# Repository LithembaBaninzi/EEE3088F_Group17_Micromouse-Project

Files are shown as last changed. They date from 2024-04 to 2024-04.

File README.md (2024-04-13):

# EEE3088F_Group17_Micromouse-Project
Designing a micromouse

## Project Overview

Welcome to the Micro-Mouse project for the year 2024! This project involves building subassemblies for your very own simplified micro-mouse, a maze-solving robot. While your micro-mouse may not match the speed of those featured in popular videos, this project serves as an exciting opportunity to delve into hardware design and some minor software components. Let's get started!



### Subsystem Specifications

Detailed specifications and requirements for each subsystem are provided, including pinouts, connector types, power requirements, and considerations for design and functionality.

### Modules Description

#### 1. The Motherboard

- **Description**: The motherboard serves as the base board connecting all other PCBs together.
- **Interface Description**: 
  - Processor board: Two 2x19 (2.54mm pin pitch) pin headers.
  - Motors: Two 2x1 (2.54mm pin pitch) pin headers.
  - Sensor board: 2x14 (2.54mm pin pitch) pin headers.
  - Power board: 2x8 (2.54mm pin pitch) pin headers.



#### 2. The Processor

- **Description**: The processor board features an STM32L476 microcontroller.
- **Interface**: Detailed pinouts are provided for connections.



#### 3. Power Module

- **Description**: Responsible for powering the entire system and charging the battery.
- **Requirements**:
  - Operate 2 motors within specified parameters.
  - Provide analog connection for battery voltage monitoring.
  - Charge the battery from the 5V input pin.
  - Include an ON/OFF switch.



#### 4. Sensor Module

- **Description**: Responsible for detecting/sensing objects in the micro-mouse's path.
- **Requirements**:
  - Detect obstacles in front and possibly on the sides.
  - Design for reliability and power efficiency.
  - Interface with the processor to indicate sensed obstacles.



#### The maze
The maze will have dead ends, multiple paths to the finishing area with each pixel being a 200mm square.
There are multiple paths to get to the goal.
An example is provided below:



## Resources

- [Veritasium Video](https://www.youtube.com/watch?v=JnkMyfQ5YfY) - Watch this video to understand the concept of a micro-mouse.
- Additional resources and documentation are provided within the project repository.

## Conclusion

This README provides an overview of the Micro-Mouse project for 2024, outlining the objectives, module descriptions, and project requirements. Each subsystem has specific tasks and considerations to ensure successful integration into the micro-mouse design. For further details, refer to the project documentation and resources provided. Happy building!
```

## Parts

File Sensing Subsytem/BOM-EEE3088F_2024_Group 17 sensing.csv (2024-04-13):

Comment | Designator | Footprint | LCSC
TEFT4300 | F_R1,L_R1,R_R2 | XDCR_TEFT4300 | C118301
100k | R_FR3,R_LR3,R_RR3 | R_0805_2012Metric | C149504
82 | R_FPD1,R_LPD1,R_RPD1 | R_0805_2012Metric | C17408
10k | R_FR2,R_LR2,R_RR2 | R_0805_2012Metric | C17414
150 | R_F1,R_L1,R_R1 | R_0805_2012Metric | C17471
1.8k | R_FR1,R_LR1,R_RR1 | R_0805_2012Metric | C17513
13 | R_F_EM1,R_L_EM1,R_R_EM1 | R_0805_2012Metric | C17544
4.7u | C_EM1,C_EM2,C_EM5 | C_0805_2012Metric | C1779
2N2222A | FQ1,LQ1,RQ1 | TO92254P470H750-3 | C20616319
0.1u | C_EM3,C_EM4,C_EM6 | C_0805_2012Metric | C49678
TSAL4400 | F_LED1,L_LED1,R_LED1 | LED_D3.0mm_Horizontal_O1.27mm_Z2.0mm_IRBlack | C94135
JP9 | 10k_JP3 | SolderJumper-2_P1.3mm_Open_RoundedPad1.0x1.5mm
TP3 | VoutL_TP1 | TestPoint_Pad_D2.0mm
JP5 | 10k_JP1 | SolderJumper-2_P1.3mm_Open_RoundedPad1.0x1.5mm
IcL_TP | TP1 | TestPoint_Pad_D2.0mm
TP6 | VoutR_TP1 | TestPoint_Pad_D2.0mm
TP4 | VoutF_TP1 | TestPoint_Pad_D2.0mm
JP6 | 10k_JP2 | SolderJumper-2_P1.3mm_Open_RoundedPad1.0x1.5mm

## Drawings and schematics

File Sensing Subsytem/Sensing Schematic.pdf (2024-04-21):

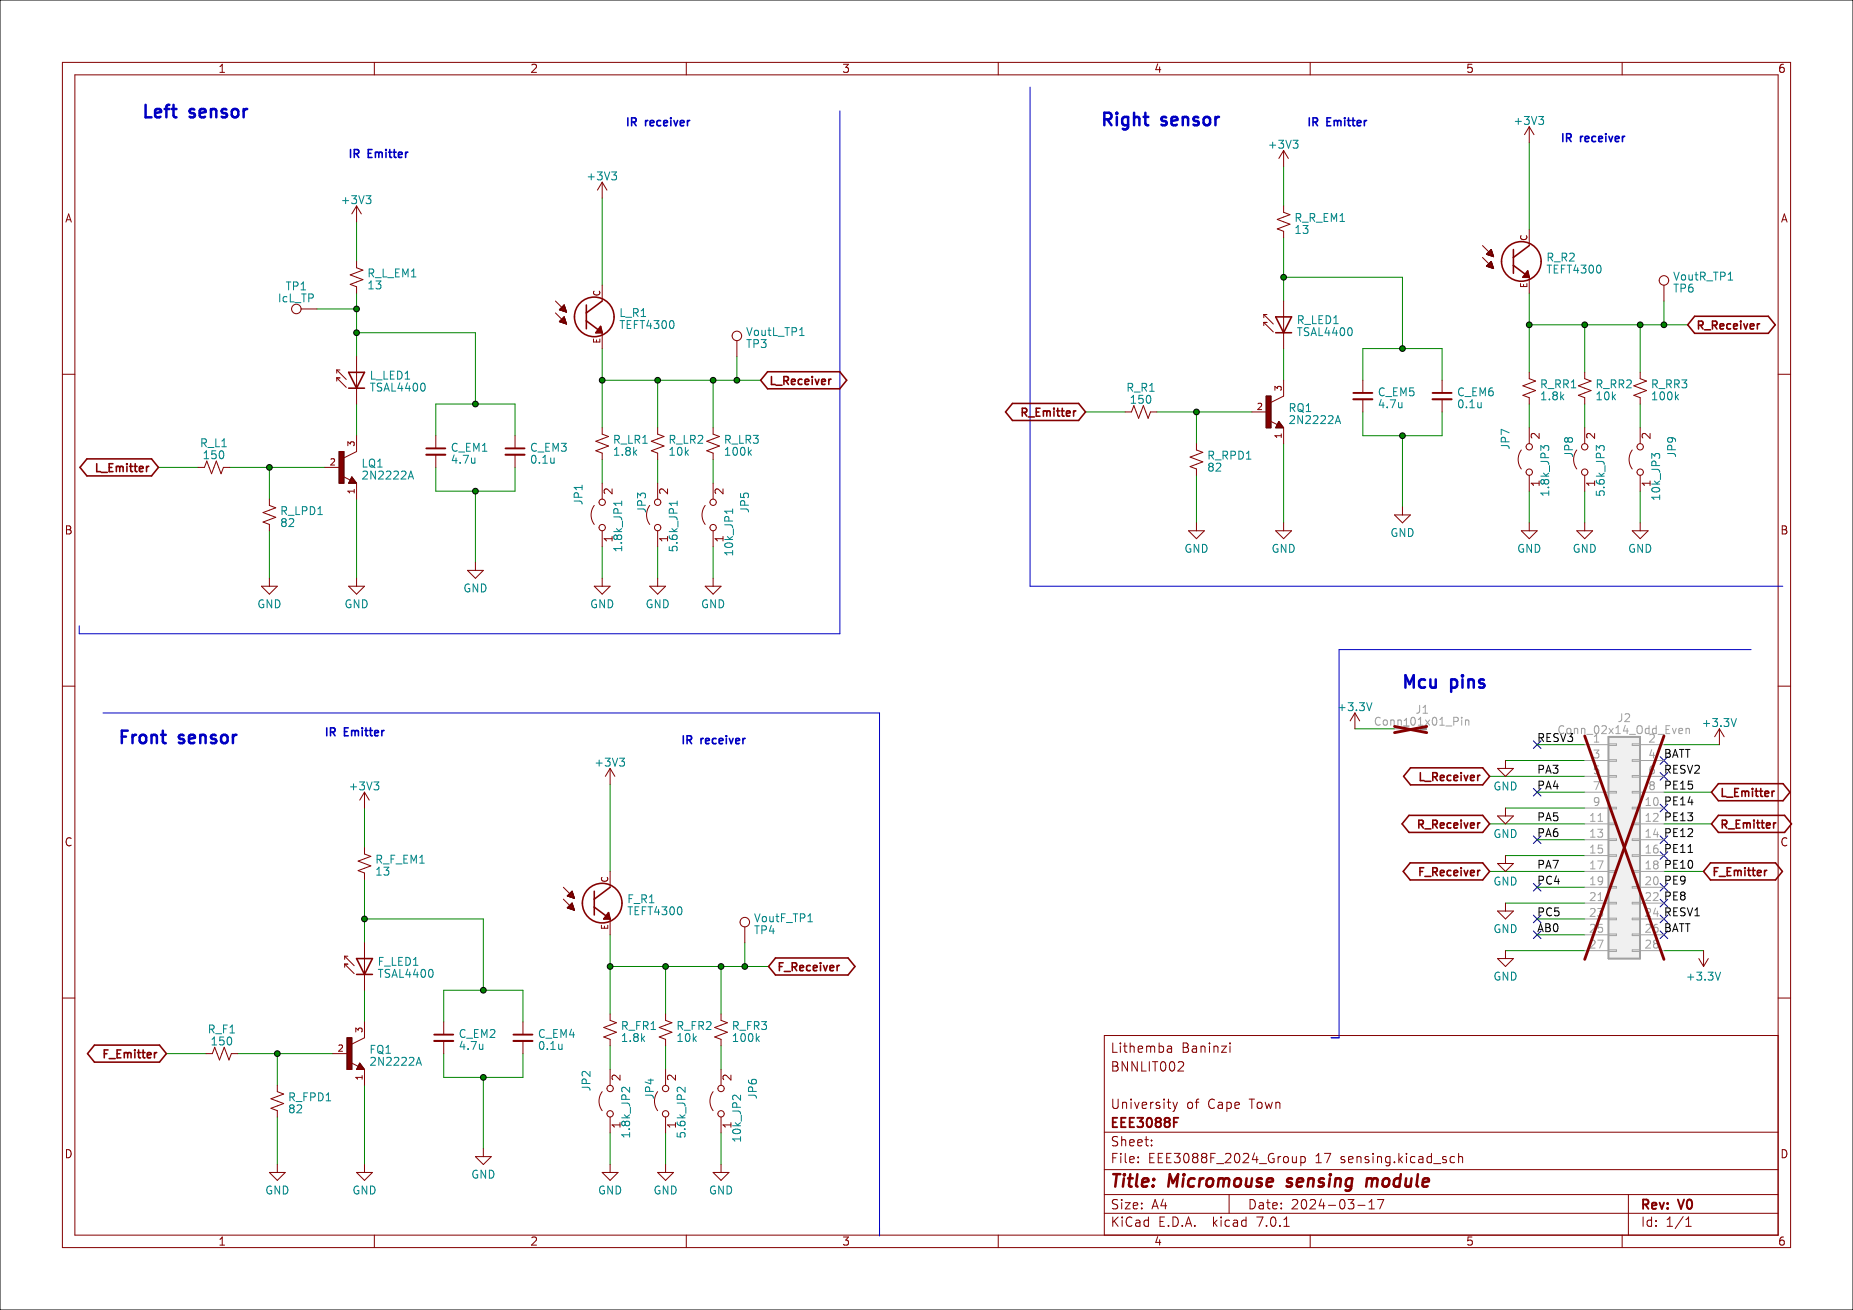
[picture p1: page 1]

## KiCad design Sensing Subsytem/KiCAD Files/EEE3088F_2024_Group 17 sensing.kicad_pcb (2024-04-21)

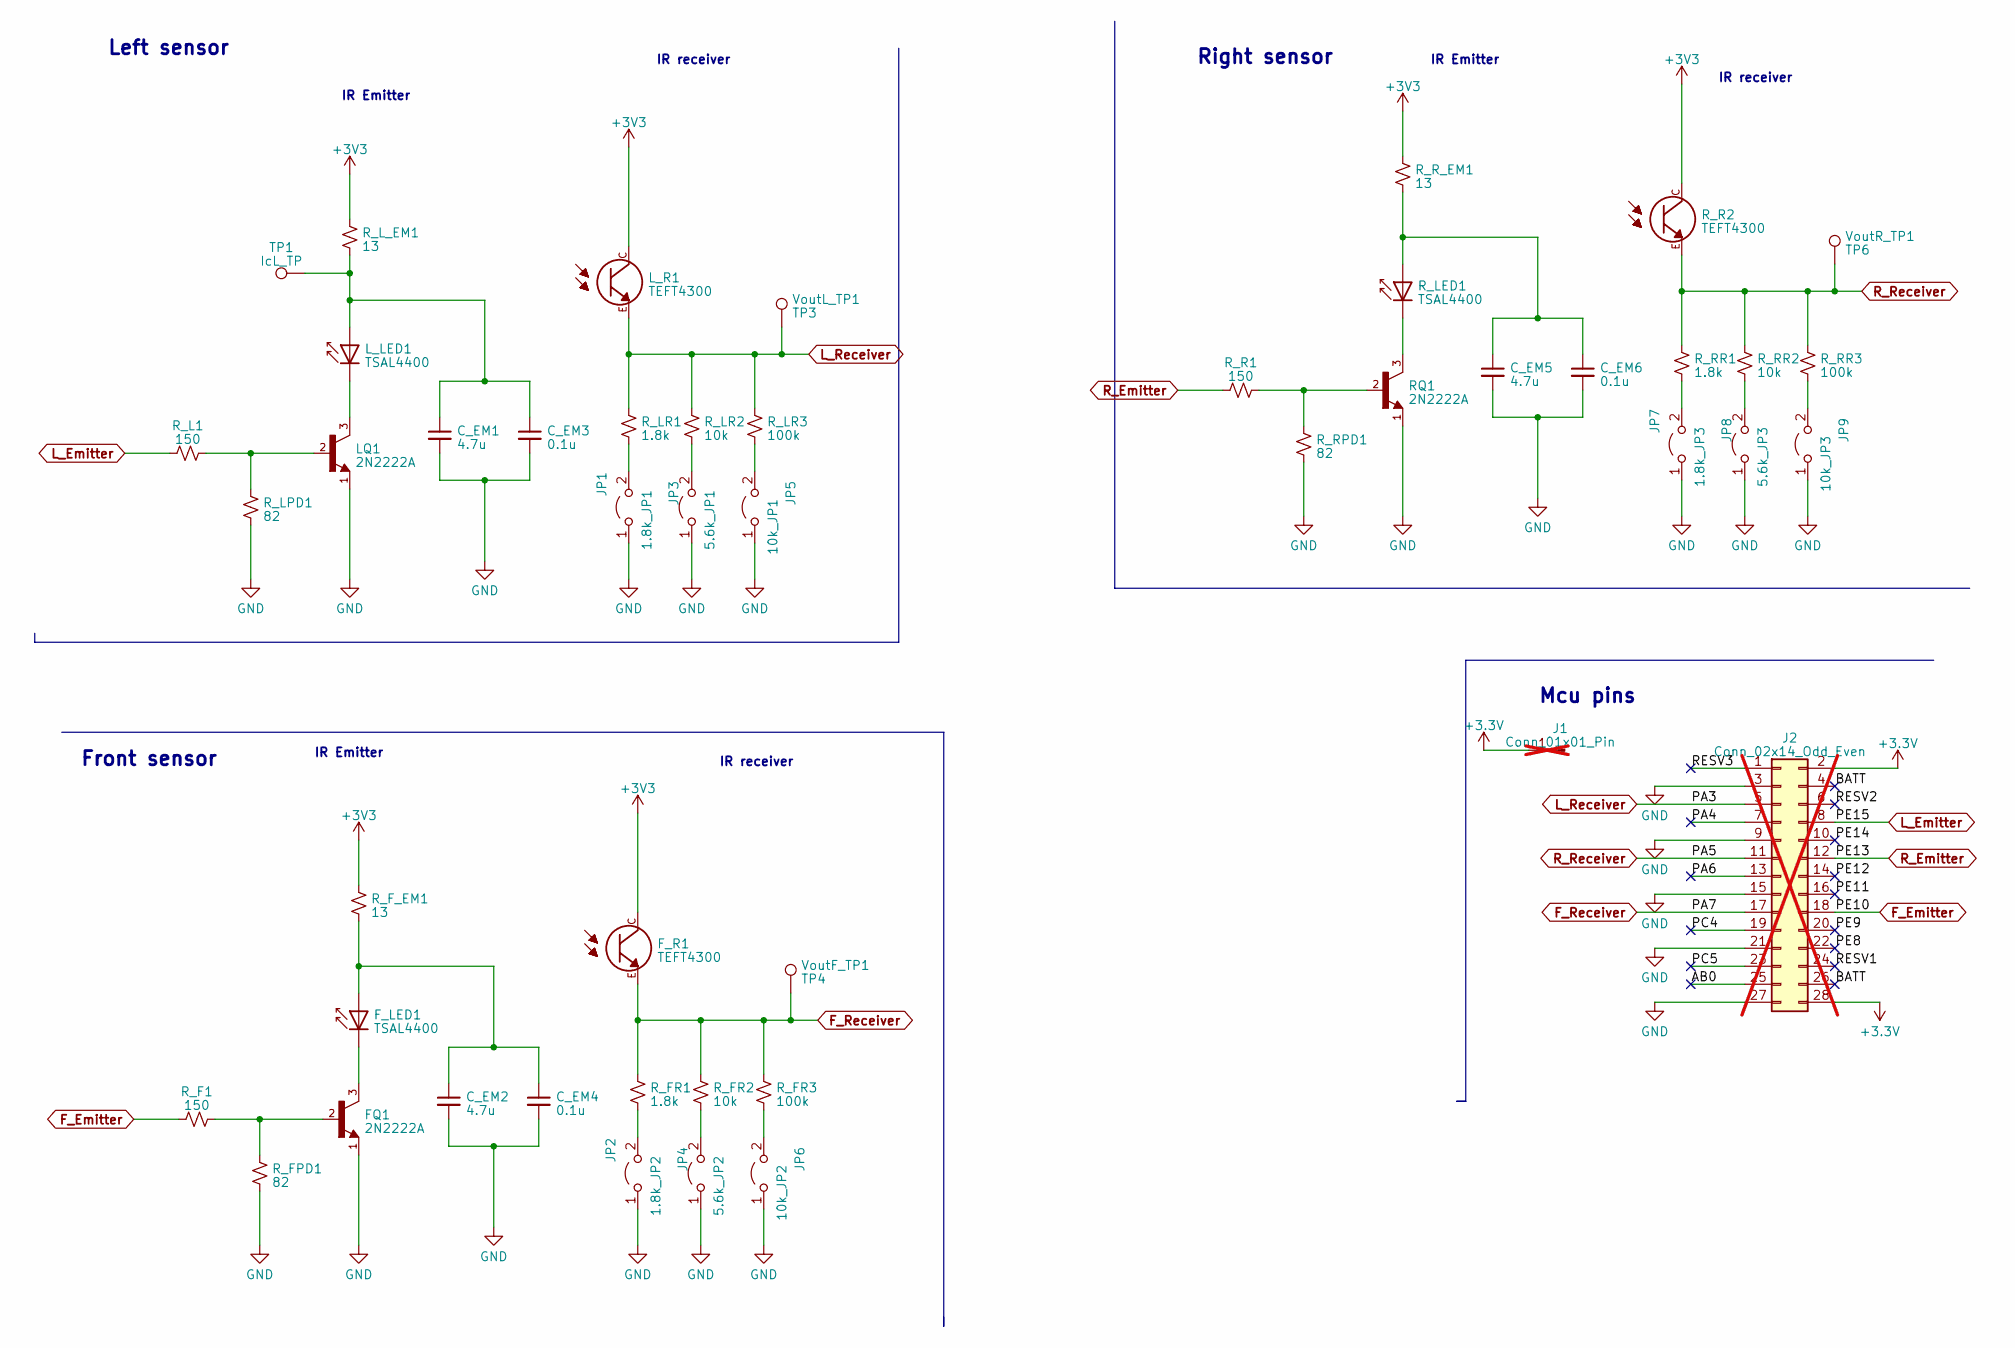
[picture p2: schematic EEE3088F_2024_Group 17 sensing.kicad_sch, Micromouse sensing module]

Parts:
1.8k_JP1: JP1; SolderJumper-2_P1.3mm_Open_RoundedPad1.0x1.5mm
1.8k_JP2: JP2; SolderJumper-2_P1.3mm_Open_RoundedPad1.0x1.5mm
1.8k_JP3: JP7; SolderJumper-2_P1.3mm_Open_RoundedPad1.0x1.5mm
5.6k_JP1: JP3; SolderJumper-2_P1.3mm_Open_RoundedPad1.0x1.5mm
5.6k_JP2: JP4; SolderJumper-2_P1.3mm_Open_RoundedPad1.0x1.5mm
5.6k_JP3: JP8; SolderJumper-2_P1.3mm_Open_RoundedPad1.0x1.5mm
10k_JP1: JP5; SolderJumper-2_P1.3mm_Open_RoundedPad1.0x1.5mm
10k_JP2: JP6; SolderJumper-2_P1.3mm_Open_RoundedPad1.0x1.5mm
10k_JP3: JP9; SolderJumper-2_P1.3mm_Open_RoundedPad1.0x1.5mm
C_EM1, C_EM2, C_EM5: 4.7u; C_0201_0603Metric
C_EM3, C_EM4, C_EM6: 0.1u; C_0201_0603Metric
FQ1: 2N2222A; TO92254P470H750-3; PARTREV N/A
F_LED1: TSAL4400; LED_D3.0mm_Horizontal_O1.27mm_Z2.0mm_IRBlack
F_R1: TEFT4300; XDCR_TEFT4300
J1: Conn_01x01_Pin; PinHeader_1x01_P2.54mm_Vertical; not fitted
J2: Conn_02x14_Odd_Even; PinHeader_2x14_P2.54mm_Vertical; not fitted
LQ1: 2N2222A; TO92254P470H750-3; PARTREV N/A
L_LED1: TSAL4400; LED_D3.0mm_Horizontal_O1.27mm_Z2.0mm_IRBlack
L_R1: TEFT4300; XDCR_TEFT4300
RQ1: 2N2222A; TO92254P470H750-3; PARTREV N/A
R_F1: 150; R_0805_2012Metric
R_FPD1: 82; R_0805_2012Metric
R_FR1: 1.8k; R_0805_2012Metric
R_FR2: 10k; R_0805_2012Metric
R_FR3: 100k; R_0805_2012Metric
R_F_EM1: 13; R_0805_2012Metric
R_L1: 150; R_0805_2012Metric
R_LED1: TSAL4400; LED_D3.0mm_Horizontal_O1.27mm_Z2.0mm_IRBlack
R_LPD1: 82; R_0805_2012Metric
R_LR1: 1.8k; R_0805_2012Metric
R_LR2: 10k; R_0805_2012Metric
R_LR3: 100k; R_0805_2012Metric
R_L_EM1: 13; R_0805_2012Metric
R_R1: 150; R_0805_2012Metric
R_R2: TEFT4300; XDCR_TEFT4300
R_RPD1: 82; R_0805_2012Metric
R_RR1: 1.8k; R_0805_2012Metric
R_RR2: 10k; R_0805_2012Metric
R_RR3: 100k; R_0805_2012Metric
R_R_EM1: 13; R_0805_2012Metric
TP1: IcL_TP; TestPoint_Pad_D2.0mm
VoutF_TP1: TP4; TestPoint_Pad_D2.0mm
VoutL_TP1: TP3; TestPoint_Pad_D2.0mm
VoutR_TP1: TP6; TestPoint_Pad_D2.0mm

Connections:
+3.3V: J1.1, J2.2, J2.28
+3V3: F_R1.C, L_R1.C, R_F_EM1.1, R_L_EM1.1, R_R2.C, R_R_EM1.1
/AB0: J2.25
/BATT: J2.4, J2.26
/PA4: J2.7
/PA6: J2.13
/PC4: J2.19
/PC5: J2.23
/PE8: J2.22
/PE9: J2.20
/PE11: J2.16
/PE12: J2.14
/PE14: J2.10
/RESV1: J2.24
/RESV2: J2.6
/RESV3: J2.1
F_Emitter: J2.18, R_F1.1
F_Receiver: F_R1.E, J2.17, R_FR1.1, R_FR2.1, R_FR3.1, VoutF_TP1.1
GND: 1.8k_JP1.1 (A), 1.8k_JP2.1 (A), 1.8k_JP3.1 (A), 5.6k_JP1.1 (A), 5.6k_JP2.1 (A), 5.6k_JP3.1 (A), 10k_JP1.1 (A), 10k_JP2.1 (A), 10k_JP3.1 (A), C_EM1.2, C_EM2.2, C_EM3.2, C_EM4.2, C_EM5.2, C_EM6.2, FQ1.1, J2.3, J2.9, J2.15, J2.21, J2.27, LQ1.1, RQ1.1, R_FPD1.2, R_LPD1.2, R_RPD1.2
L_Emitter: J2.8, R_L1.1
L_Receiver: J2.5, L_R1.E, R_LR1.1, R_LR2.1, R_LR3.1, VoutL_TP1.1
unnamed: 1.8k_JP1.2 (B), R_LR1.2
unnamed: 1.8k_JP2.2 (B), R_FR1.2
unnamed: 1.8k_JP3.2 (B), R_RR1.2
unnamed: 5.6k_JP1.2 (B), R_LR2.2
unnamed: 5.6k_JP2.2 (B), R_FR2.2
unnamed: 5.6k_JP3.2 (B), R_RR2.2
unnamed: 10k_JP1.2 (B), R_LR3.2
unnamed: 10k_JP2.2 (B), R_FR3.2
unnamed: 10k_JP3.2 (B), R_RR3.2
unnamed: FQ1.2, R_F1.2, R_FPD1.1
unnamed: C_EM2.1, C_EM4.1, F_LED1.2 (A), R_F_EM1.2
unnamed: FQ1.3, F_LED1.1 (K)
unnamed: LQ1.2, R_L1.2, R_LPD1.1
unnamed: C_EM1.1, C_EM3.1, L_LED1.2 (A), R_L_EM1.2, TP1.1
unnamed: LQ1.3, L_LED1.1 (K)
unnamed: RQ1.2, R_R1.2, R_RPD1.1
unnamed: C_EM5.1, C_EM6.1, R_LED1.2 (A), R_R_EM1.2
unnamed: RQ1.3, R_LED1.1 (K)
R_Emitter: J2.12, R_R1.1
R_Receiver: J2.11, R_R2.E, R_RR1.1, R_RR2.1, R_RR3.1, VoutR_TP1.1

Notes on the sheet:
IR Emitter
IR receiver
Right sensor
Left sensor
Mcu pins
Front sensor

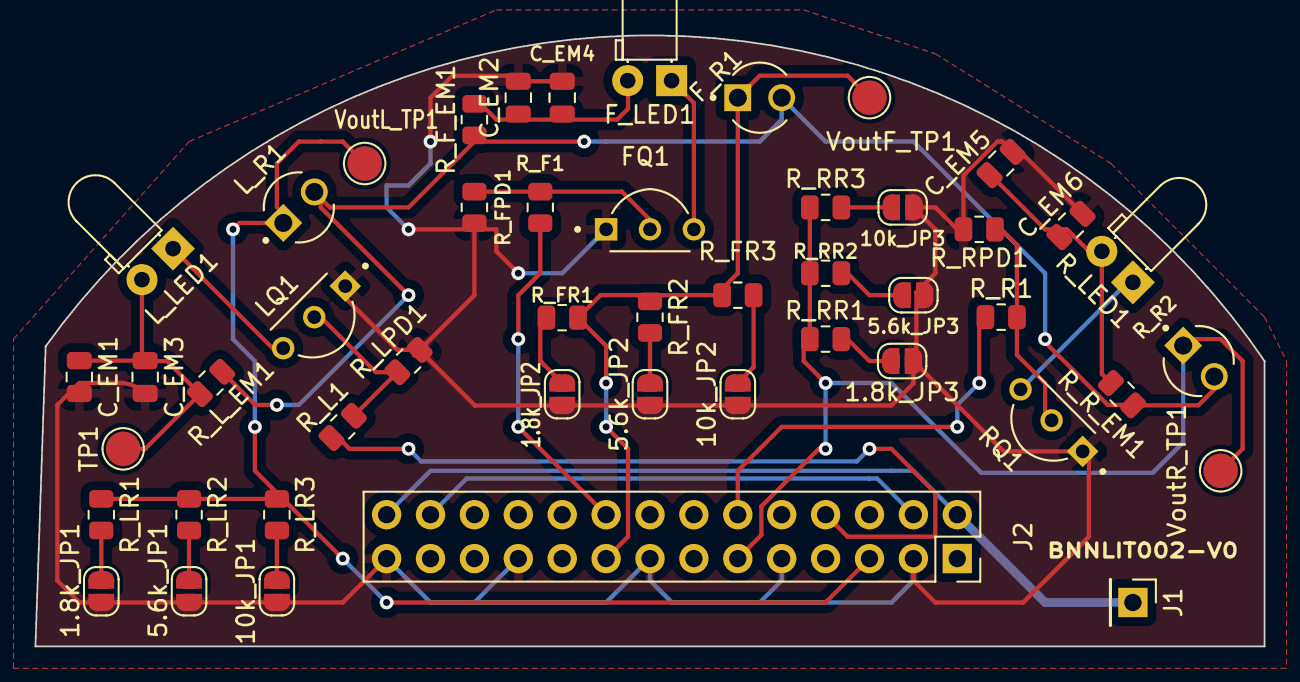
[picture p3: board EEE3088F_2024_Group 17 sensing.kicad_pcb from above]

Board: 2 copper layers, 71.1 x 35.4 mm, 48 parts (0 on the bottom side), 28 nets.

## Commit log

2024-04-04 Create Power Subsystem
2024-04-04 Adding gerber files, CPL file and BOM
    [BOM-EEE3088F_2024_Group 17 sensing.csv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]
2024-04-21 Uploading KiCad Files
    [EEE3088F_2024_Group 17 sensing.kicad_pcb, EEE3088F_2024_Group 17 sensing.kicad_sch]
2024-05-17 Adding STM32 Cube IDE
    Zip file containing all the code used for the sensing module
